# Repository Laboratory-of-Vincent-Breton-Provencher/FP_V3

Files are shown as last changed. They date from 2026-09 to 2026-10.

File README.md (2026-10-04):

# Multi-fiber Fiber Photometry System (FP V3)

A fiber photometry system that records from more than one fiber at a time. The system 
was developed by the VBP lab and has been in use since 2022.

If you use the system in your research **please cite:**
Bouchard S, Boutin J, Lévesque M, et al. *Region-specific weighting of sensory intensity
and reward prediction error by dopamine signals.* iScience, 2026; 29.
https://doi.org/10.1016/j.isci.2026.117130

> A STAR Protocols paper for using this system, implanting the fibers, and training head-fixed
> mice is in preparation.

---

## Contents

- [1. System overview](#1-system-overview)
- [2. Repository contents](#2-repository-contents)
- [3. Optical path](#3-optical-path)
- [4. Electronics](#4-electronics)
- [5. Software installation](#5-software-installation)
- [6. First-time configuration](#6-first-time-configuration)
- [7. Recording](#7-recording)
- [8. Output data](#8-output-data)
- [9. Validating a recording](#9-validating-a-recording)
- [10. Troubleshooting](#10-troubleshooting)
- [11. Known limitations and to-do](#11-known-limitations-and-to-do)

---

## 1. System overview

<p align="center">
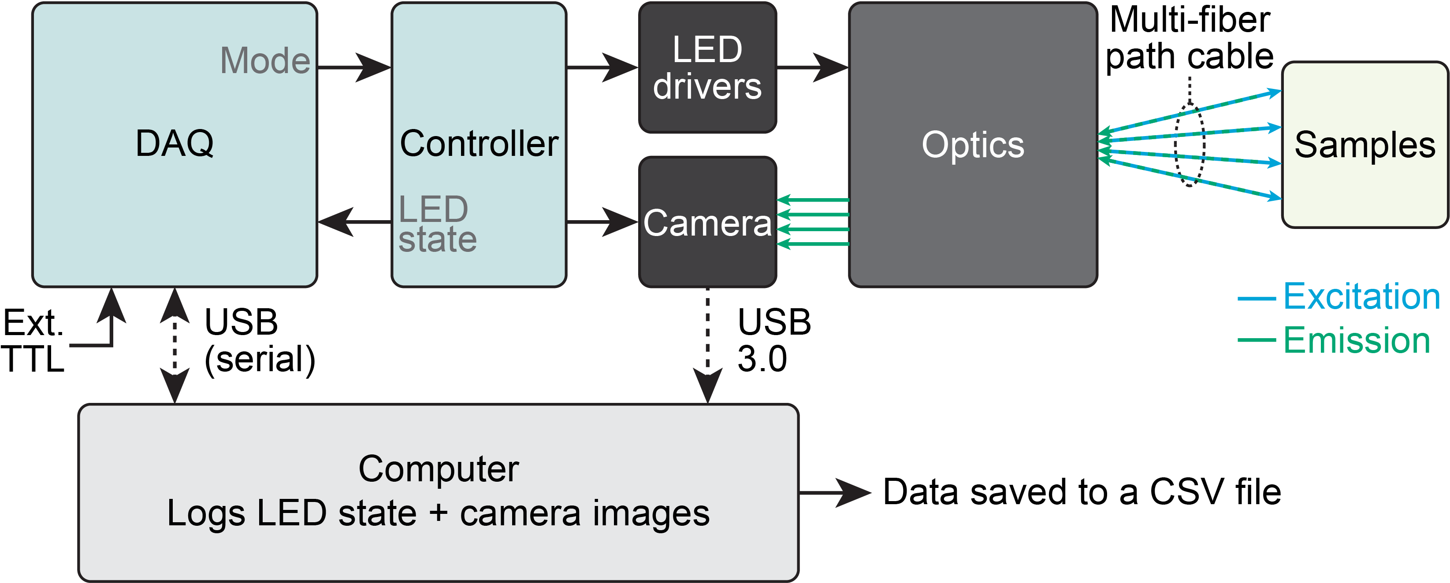
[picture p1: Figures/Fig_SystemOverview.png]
Overview


**Figure 1. Overview of system components**
</p>

Two microcontrollers, a camera and a set of LED drivers run the system, with a computer recording the result.

The **DAQ** (Arduino UNO) is the only board connected to the computer. It receives the requested mode from 
Bonsai over USB and passes it to the controller. It also reads the LED sate from the controller and sends it to the computer,
together with the state of an external TTL input (D8) for events from a behaviour system.

The **controller** (Arduino Nano) triggers the **camera** and switches the **LED drivers** so that each frame is illuminated 
by exactly one wavelength.

The **optics** focus the light sources (405 and 470 nm) onto the back of a multi-core patch cable, and the fluorescence 
emitted by the sample returns along the same path to the camera.

The **computer** runs a Bonsai script to extract the mean intensity inside one ROI per fiber and pair it with the LED state, 
and writes everything to a CSV file. 

<p align="center">
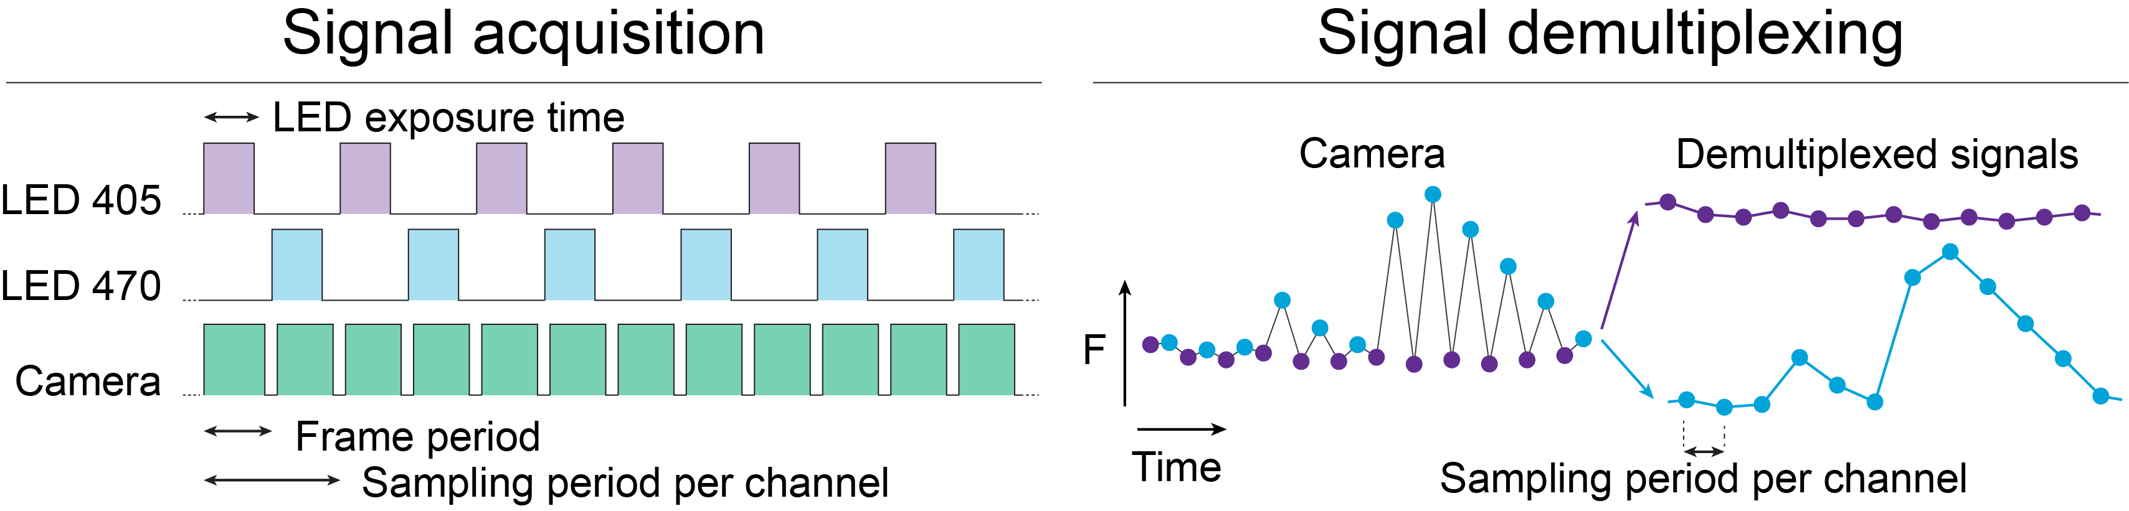
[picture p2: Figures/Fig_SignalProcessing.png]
Signal processing


**Figure 2. Signal acquisition and demultiplexing.**
</p>

The controller triggers the camera at 40 Hz and alternates the LEDs so that each frame 
is illuminated by exactly one wavelength. The exposure sits inside the LED pulse, and 
each wavelength is therefore acquired at 20 Hz. 

The raw intensity measured in one fiber ROI alternates between the two wavelengths from 
frame to frame. Because the state of every LED is recorded alongside each frame, the trace 
is split afterwards into one signal per wavelength.

---

## 2. Repository contents

| File | Purpose |
|---|---|
| `FP_camLED_controller.ino` | Controller sketch (Arduino **Nano**). Camera trigger and LED sequencing. |
| `FP_DAQ.ino` | DAQ sketch (Arduino **UNO**). Mode control, per-frame logging, external TTL. |
| `CustomFP_1chan_4Fibers.bonsai` | Bonsai workflow: camera, ROI extraction, serial parsing, CSV writing, live display. |
| `Part Lists/Optical paths.xlsx` | Optical components. |
| `Part Lists/Electronics.xlsx` | Electronic components. |
| `3D print/` | Cases and holders for the Arduinos and the protoboard. |

> **TODO:** add the wiring diagram, an optical path drawing, a photo of the setup, and the
> SpinView settings screenshots (Settings, Image Format, GPIO).

---

## 3. Optical path

<p align="center">
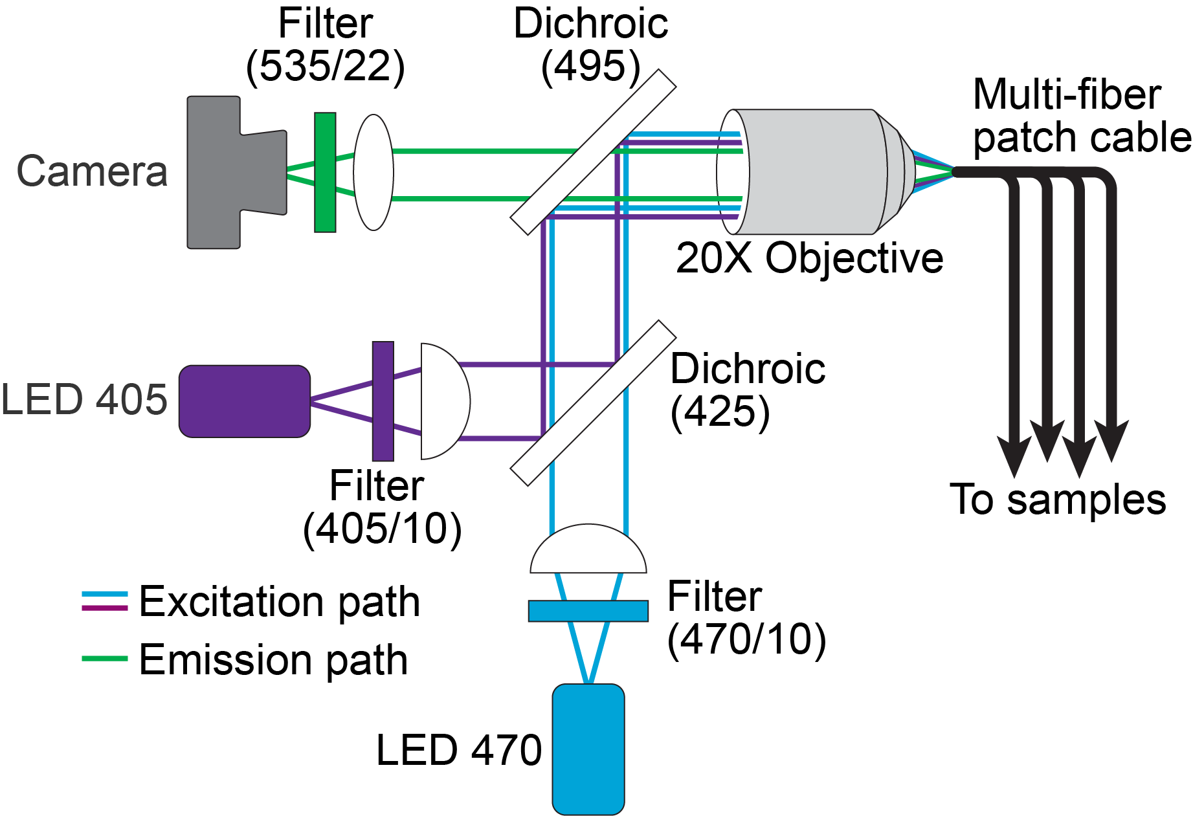
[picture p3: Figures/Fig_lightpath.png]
Optical path

</p>

**Figure 3. Optical path.**

Excitation light from a 405 nm LED (isosbestic reference) and a 470 nm LED (signal) passes
through a bandpass filter and a collimating lens (plano-convex, 25 mm focal length). A
longpass dichroic (425 nm) combines the two beams. A second longpass dichroic (495 nm), 
reflects them into the objective (10X air NA 0.25, or 20X air NA 0.4) and
into the fiber.

Light emitted by the specimen returns along the same path, passes through the 495 nm
dichroic, and is filtered by a bandpass filter before reaching the sCMOS camera through 
an achromatic tube lens.

The 405 nm channel serves as the isosbestic point for most sensors, and is used
to correct the 470 nm signal for motion artefacts. With green detection around 535 nm, the
system works with calcium sensors such as GCaMP, and with neuromodulator
sensors such as GRAB-DA or nLightG.

### Assembly

See the [list of optical components](Part%20Lists/Optical%20paths.csv).

<p align="center">
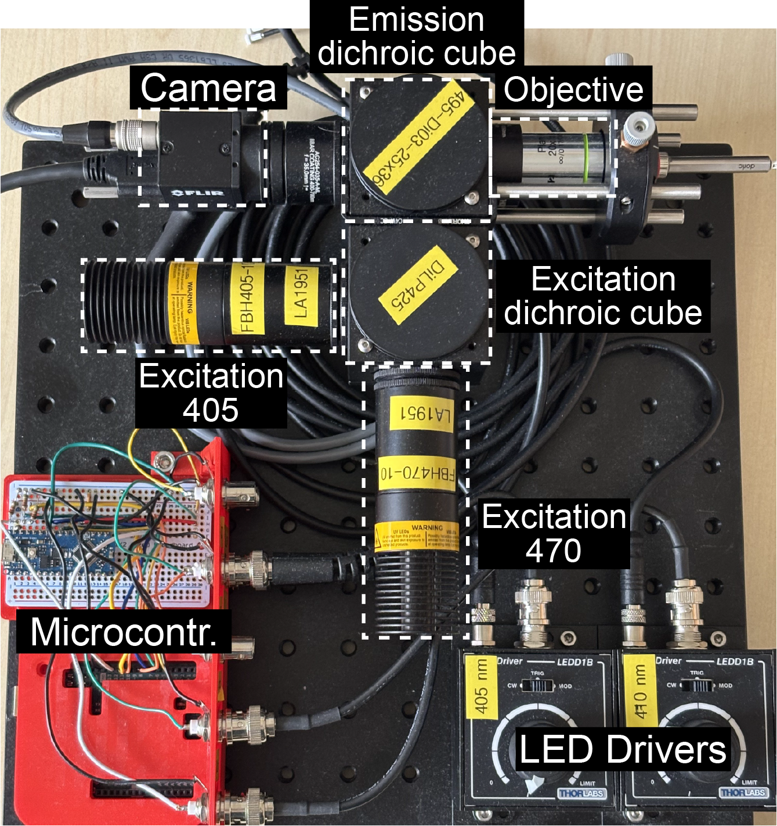
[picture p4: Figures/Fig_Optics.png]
Optic setup

</p>

**Figure 4. The assembled set up.** The optical path, the LED drivers and the microcontrollers
mounted on a single breadboard.

1. **Assemble both dichroic cubes** (Thorlabs #C4W). Fix the bottom plates (B1C). Attach the
   dichroic filter holder (FFM1) to the rotating platform (B3C) and temporarily fix each
   platform on top of the cubes. Join the cubes with the C4W-CC piece. Mount the cubes on
   the breadboard with optical posts.
2. **Build the excitation arms.** In a 1½ inch lens tube, insert the bandpass filter for that wavelength. 
   Add the collimating lens, flat side toward the LED, about 25 mm
   from the source, which is its focal length. Note that a Thorlabs mounted LED sits
   slightly inside the tube; use its spec sheet to calculate the position within the tube.
   Thorlabs spanner tools have graduations that help.

   To check collimation, hold the finished tube about 50 cm from a wall and turn the LED
   on: the spot should be roughly the same diameter as the tube's aperture (1 inch) and
   should not change noticeably as you move the tube closer or further away. A spot that
   grows with distance means the lens is too close to the LED; one that converges first
   means it is too far.
   
   Screw each tube into its cube using a
   lens tube coupler with two retaining rings (SM1T2), then add the mounted LEDs.
3. **Install the dichroics.** Insert the dichroics on each rotating platform (see step 1). The coated side must face
   the light sources. Adjust the angle of each dichroic so that both LEDs reach the
   back aperture of the objective.
4. **Assemble the objective and fiber adapter**. Screw a short lens tube into the cube, then
   the objective adapter around the objective and into the tube. The objective must be
   tight and immobile. Add the cage mount and the fiber adapter.
5. **Assemble the emission path**. Screw in a lens tube coupler with two retaining rings (SM1T2) to the emission dichroic cube.
   Screw in the achromat lens (already mounted in a tube). Insert a
   bandpass filter in a short lens tube and screw next to the achromat, and then the camera. 

### Alignment

Perform these alignment steps in the dark. The target output is **30–50 µW per fiber per
wavelength**, and the fiber bundle must stay inside the camera frame throughout.

1. **Align the dichroics.** Remove the fiber adapter (CXY1A) and place a power meter in
   front of the objective. Turn on the 470 nm LED only and adjust the angle of the 495
   dichroic to maximise the power at the objective, then secure its rotating plate. Next, turn on the 405 nm
   LED only and adjust the angle of the 425 dichroic to maximise the power. Keep this order: the 470 nm path depends only on the 495 dichroic, whereas
   the 405 nm path passes through both.
2. **Focus the fiber adapter on the camera.** Put the fiber adapter back in place and
   connect an optical patch cable. Slide the adapter along the cage rods to move it in Z
   until the fiber face is in focus on the camera, then secure it in place.
3. **Maximise the power in one fiber.** With a single fiber connected, adjust x and y with
   the CXY1A screws to maximise the output power. Repeat for every wavelength. The optimum
   position may differ slightly between 405 and 470 nm; in that case, split the difference
   between the two.
4. **Balance the fibers.** With several fibers connected, repeat step 3 to minimise the
   power differences between them.

---

## 4. Electronics

You will need a half-size protoboard, female BNC connectors and cables. See the [list of electronics](Part%20Lists/Electronics.csv). 
The case is 3D printed; the model is [available here](3D%20print/).

<p align="center">
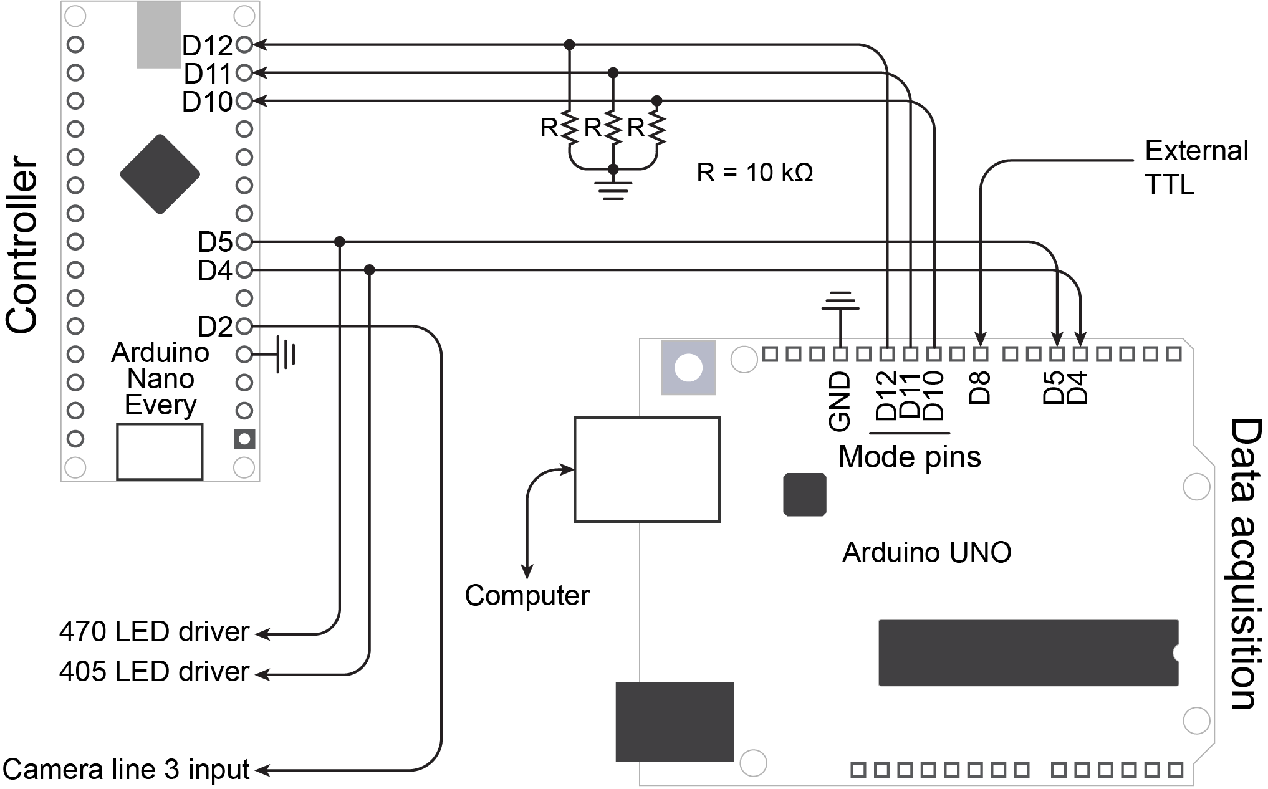
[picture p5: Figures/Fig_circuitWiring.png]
Wiring

</p>

**Figure 5. Circuit wiring.** Note: all components should be connected to a common ground.

### 4.1 Controller (Arduino Nano) — `FP_camLED_controller.ino`

Reads the requested mode on D10–D12 and drives the camera and the LED drivers on a fixed
40 Hz schedule. Upload once; it then runs from any USB power source. LED drivers need to be running in trigger mode (TRIG).

| Pin | Direction | Connected to |
|---|---|---|
| D2 | out | Camera trigger (both cameras, Line 3 in SpinView).  For more pin info [click here](https://softwareservices.flir.com/BFS-U3-50S5/latest/50-Quality/GPIOTest.htm)|
| D4 | out | 405 nm LED driver, and DAQ D4 |
| D5 | out | 470 nm LED driver, and DAQ D5 |
| D10, D11, D12 | in | Mode lines V, B, G from DAQ D10, D11, D12 |
| GND | — | Common ground with DAQ, camera and LED drivers |

Frame timing at 40 Hz:

```
        │◄────────────── 25.000 ms ──────────────►│
  LED   ┌──────────────────────────────┐          ┌───────────────
        │        24.5 ms excitation    │  500 µs  │  next LED
  ──────┘                              └──────────┘
 Trigger ──────┐                              ┌──────────────────
  (D2)         │  LOW while the LED is on     │
               └──────────────────────────────┘
        ▲ frame start (FALLING edge)
```

### 4.2 DAQ (Arduino UNO) — `FP_DAQ.ino`

Connected to the computer over USB. It sets the mode for the controller, watches the LED
driver lines, and prints one line per frame at **250000 baud**.

| Pin | Direction | Connected to |
|---|---|---|
| D4, D5 | in | Controller's 405 / 470 driver lines |
| D8 | in | External TTL (e.g. trial start from a behaviour system) |
| D10, D11, D12 | out | Mode lines V, B, G to controller D10, D11, D12. These required pull-down resistors (10 kΩ to ground). |
| GND | — | Common ground |

### 4.3 Modes and serial commands

Send one character to the DAQ, from Bonsai or from the Arduino IDE serial monitor. Upper or
lower case; anything else, including line endings, is ignored.

| Command | Mode (VBG) | LEDs cycled, one per frame | Per-channel rate at 40 fps |
|---|---|---|---|
| `0` | 000 | OFF | — |
| `V` | 100 | 405 | 40 Hz |
| `B` | 010 | 470 | 40 Hz |
| `G` | 001 | 565 | 40 Hz |
| `Y` | 110 | 405, 470 | 20 Hz |
| `M` | 101 | 405, 565 | 20 Hz |
| `C` | 011 | 470, 565 | 20 Hz |
| `X` | 111 | 405, 470, 565 | 13.3 Hz |

The system boots in OFF and stays there until a command arrives, so nothing is illuminated
or triggered until you ask for it. Changing mode restarts the LED cycle at the first
enabled wavelength, which is why each recording block starts on 405.

> **Note.** The controller and the DAQ implement modes for a third excitation source
> (565 nm), but the current setup uses only 405 and 470 nm. 
> 

### 4.4 Line format sent by the DAQ

One line per frame, emitted at the LED onset. There are 8 fields:

```
V,B,G,TTL,mode,FLAG,t_onset,t_ttl
1,0,0,0,110,07,283963284,0
```

| Field | Meaning |
|---|---|
| `V`, `B`, `G` | 1 for the LED that is on for this frame (read from the driver lines) |
| `TTL` | 1 if the external TTL is HIGH now, or rose at any point since the previous frame |
| `mode` | Commanded mode, 3 digits. May lead the LEDs by one frame at a mode switch |
| `FLAG` | Frame counter, 0–99, wraps. Detects lines lost on the serial link |
| `t_onset` | Arduino `micros()` at the LED onset of this frame |
| `t_ttl` | Arduino `micros()` of the TTL rising edge reported on this line, 0 if none |

---

## 5. Software installation

### 5.1 Arduino

1. Install the Arduino IDE.
2. In **Tools → Board → Boards Manager**, install the board package for your Nano. The system has been tested with the Nano Every board.
3. Upload `FP_camLED_controller.ino` to the **Nano** and `FP_DAQ.ino` to the **UNO**.
   Check the COM port for each before uploading. The controller only needs this once. Take note of the DAQ COM port. The COM port will be requested by the Bonsai script.
4. Test that the DAQ and the system can be driven without Bonsai: open the IDE serial monitor on the DAQ's port
   at **250000 baud** and type `Y` (two LEDs) or `X` (three LEDs), or `0` to stop.
   
### 5.2 Camera (Spinnaker)

1. Install `SpinnakerSDK_FULL_4.2.0.83_x64.exe`. This version works with the current
   Bonsai.Spinnaker package (see https://github.com/bonsai-rx/spinnaker). For VBP lab member, the installer is
   on our NAS. Other users should contact support at Teledyne as they no longer lists this version publicly.
2. Choose, the **full SDK** and the **Application Development** option. The GigE driver
   component can be deselected.
3. Connect the camera and confirm it streams in SpinView.
4. Apply the settings below. Anything not listed stays at its default; the Imaging Format, Processing,
   Sequencer and Features tabs are not modified.
5. Save the configuration as a user set in the camera so it survives a reconnection.

Reference configuration, for a **Blackfly S BFS-U3-04S2M** (firmware 1707.1.6.0):

**Settings tab**

| Setting | Value | Why |
|---|---|---|
| Acquisition Mode | Continuous | |
| Acquisition Frame Rate Enable | unchecked | The frame rate comes from the controller's trigger, not the camera |
| Exposure Mode | Timed | Exposure length is set here, not by the trigger pulse width |
| Exposure Auto | Off | Must be fixed, or the two wavelengths are exposed differently |
| Exposure Time | 16999 µs | Must fit inside the 24.5 ms LED pulse 17ms is what we commonly use. Issues with dropped frame increases with exposure time. |
| Gain Auto | Off | Must be fixed, for the same reason as exposure |
| Gain | 34.3 dB | Adjust per setup; see the note below |
| Gamma Enable | unchecked | Keeps the response linear, which fluorescence quantification requires |
| Black Level | 0 % | |
| Device Link Throughput Limit | 60000000 | |

**GPIO tab**

| Setting | Value | Why |
|---|---|---|
| Trigger Selector | Frame Start | |
| Trigger Mode | On | |
| Trigger Source | Line 3 | The controller's D2 output |
| Trigger Activation | Falling Edge | The trigger line idles HIGH and goes LOW for the excitation window |
| Trigger Overlap | Off | |
| Trigger Delay | 9 µs | Minimum permitted value |
| Line Selector / Line Mode | Line 0 / Input | |

### 5.3 Bonsai

Install Bonsai (tested with **2.9.1**): https://bonsai-rx.org/docs/articles/installation.html

In **Tools → Manage Packages**, install:

- `Bonsai.Spinnaker`
- `Bonsai.Vision`
- `Bonsai.Vision.Design`
- `Bonsai.Scripting.Expressions`
- `Bonsai.Gui`
- `Bonsai.Gui.ZedGraph`

---

## 6. First-time configuration

Close the serial monitor in the Arduino IDE before running Bonsai — only one program can
hold the port.

Open `CustomFP_1chan_4Fibers.bonsai` and set:

1. **Camera serial number** in the `SpinnakerCapture` node (dropdown).
2. **COM port** of the DAQ, in the `String` node feeding the `Arduino COM Port` subject
   (see step 5.1.3).
3. **Recording length** in the `N Frames` node. This is a total frame count, so at 40 fps:
   288000 = 2 h, 144000 = 1 h, 72000 = 30 min. Acquisition stops on its own at this count,
   and can also be stopped manually at any time, so set it longer than you expect to need.
4. **Start the workflow** with F5, or Workflow → Start. Check that the visualizer windows
   appear (see **Figure 6**); if they don't, which is usually the case the first time, see the note below.
5. **Turn the LEDs on** by pressing `Record`, so the fibers become visible. Without a mode
   command the LEDs stay off and the camera image is dark. The command can also be sent
   from the Arduino IDE serial monitor, but not while Bonsai holds the port.
6. **Fiber ROIs** in the `RoiActivity` node. Draw one ROI per fiber. ROI order sets the
   column names: ROI 0 → `f0_ch1`, and so on. Label each fiber physically with its ID and
   match the ROIs to those IDs. With fewer than four fibers, park the unused ROIs on an
   empty part of the image. 
   [More info on how to edit ROI here.](https://bonsai-rx.org/docs/api/Bonsai.Vision.RoiActivity.html) 
   Note: Changes to ROIs are only kept if you stop running Bonsai and save.
7. **Check for cross-talk:** block the light in front of one fiber and confirm that the
   other ROI values don't change.

**Note on visualizer windows**

<p align="center">
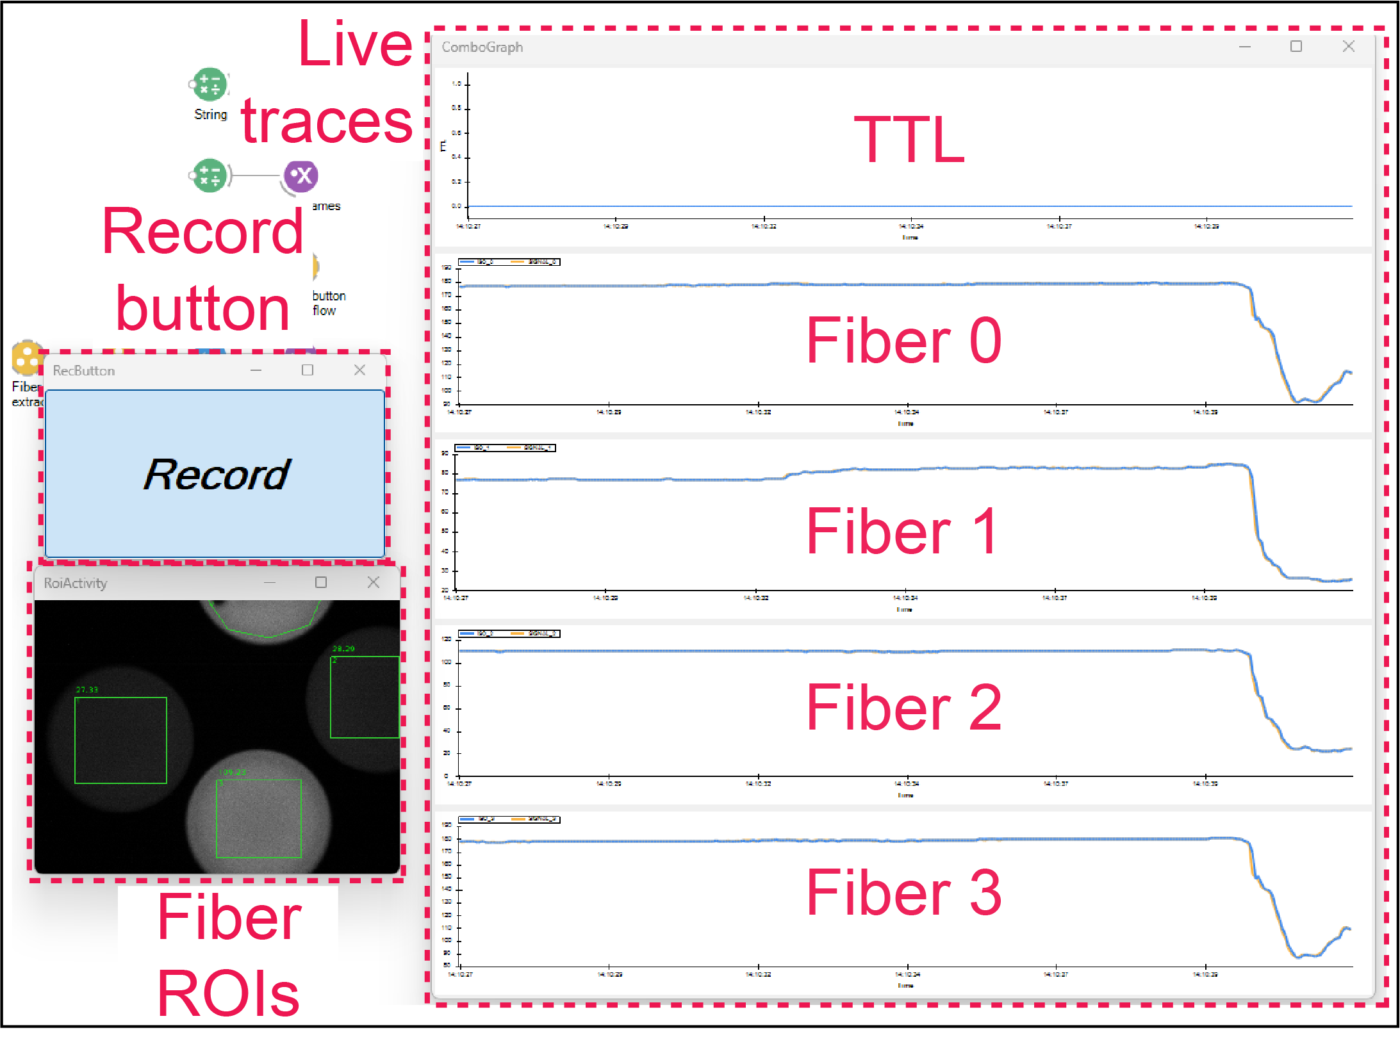
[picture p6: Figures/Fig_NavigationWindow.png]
Bonsai editor with the Explorer panel and the visualizer windows open
  
</p>

**Figure 6. Visualizer windows.** The Explorer panel, lower left, is used to navigate into
each group workflow; double-clicking a node there opens its visualizer while the workflow
runs.

The visualizer windows and their positions are stored in the
`CustomFP_1chan_4Fibers.bonsai.layout` file. If the graphs or the record button do not
appear when you start the workflow, that file is missing or out of date, and the windows
have to be opened manually:

| Window | Where | Node to double-click |
|---|---|---|
| Live traces | `Display Graph` | `ComboGraph` |
| Record button | `Rec button workflow` | `RecButton` |
| Fiber ROIs | `Fiber ROI extraction` | `RoiActivity` |

Use the Explorer panel in the lower left corner to navigate into each group. The workflow
must be running for a visualizer to open.

If double-clicking `ComboGraph` opens an empty window, the individual graphs have to be
added to it: drag each `RollingGraph` node from the `Display Graph` workflow onto the
`ComboGraph` window, starting from the top one (TTL) so they appear in the intended order.

Once all the windows are open and positioned, stop the workflow and save it (Ctrl+S) so
the layout is remembered for next time.

---

## 7. Recording

**Before recording:** Connect the fibers to the fiber adapter. With the LED driver set to 
constant current mode (CW), measure the **470 nm** output of each fiber. Adjust each of them 
into the 30–50 µW range. Put back to LED driver to trigger mode (TRIG).

1. Connect the fibers to the implanted ferrules.
2. Adjust the power on the **405 nm** channel:
   2a.Start the Bonsai workflow and press the **Record** toggle button. This sends `Y` (405/470) to the DAQ and starts the LEDs,
      the camera and the CSV writing.
   2b. Adjust the **405 nm** channel with its knob until its trace matches the 470 nm trace in
      the live graphs.
   2c. Press the **Record** toggle again to stop. Stop the Bonsai workflow and delete the files that were saved during the adjustment.
3. Start the Bonsai workflow.
4. Press the **Record** toggle button. This sends `Y` (405/470) to the DAQ and starts the LEDs,
   the camera and the CSV writing.
5. During the recording, watch the live traces and check that TTLs are being detected. If TTLs are to be recorded, confirm the cable is connected to DAQ D8.
6. Press **Record** again to stop. This sends `0`, which stops the LEDs and the triggers.
7. **Stop the Bonsai workflow.** A new CSV is only created when the workflow starts, so
   leaving it running puts the next recording in the same file.

Toggling the record button on and off during a session is safe. Each block appears in the
CSV as a continuous run of frames, separated by a gap in the timestamps, and each block
starts on 405.

---

## 8. Output data

One CSV per workflow run, named `FP_1ch_<timestamp>.csv`, with a header row.

| Column | Source | Meaning |
|---|---|---|
| `V`, `B`, `G` | DAQ | LED on for this frame |
| `TTL` | DAQ | External TTL state, as described above |
| `mode` | DAQ | Commanded mode |
| `ts_arduino` | DAQ | `micros()` at the LED onset |
| `ts_arduino_ttl` | DAQ | `micros()` of the TTL rising edge, 0 if none |
| `ts_ch1` | Camera | Camera chunk timestamp, in nanoseconds |
| `f0_ch1` … `f3_ch1` | Camera | Mean pixel intensity in each fiber ROI |
| `Channel` | Bonsai | `405`, `470` or `565`, derived from V/B/G |

To split violet and blue, filter on `Channel` rather than on row parity: the sequence
restarts at 405 after every mode change, so parity is not reliable across blocks.

**Choose one clock and stay with it.** The Arduino and camera clocks differ by roughly
470 ppm, which is about 3.4 s over a 2 hour recording. `ts_ch1` is the one attached to the
images and is the better choice for analysis. `ts_arduino` is the right one for lining up
external TTL events, since `ts_arduino_ttl` comes from the same clock.

> **Note** We need to add info on how signal is processed. Also include a python script for showing basic processing of data.

---

## 9. Validating a recording

**Channel labelling.** The camera is configured to trigger on the falling edge, which is
the start of the excitation window, so each image corresponds to the LED named on its own
row. Re-check this after any change to the trigger settings or to the controller sketch:
run in `Y` mode and block the 405 nm LED, or turn its driver output down to zero. In the
CSV, every row labelled `405` should then be dark and every `470` row bright. If the dark
rows carry the `470` label instead, the images are offset by one frame from their labels,
which means the trigger activation has been switched to the rising edge.

**Dropped frames.** Within a continuous block, consecutive `ts_arduino` values should
differ by 25000 µs. A 50000 µs step means a frame was lost. Gaps of hundreds of
milliseconds are just the record button being toggled.

**Image and log alignment.** For every row, the change in `ts_arduino` and the change in
`ts_ch1 / 1000` should agree to within a few tens of microseconds. A sudden jump to a full
frame period means the image and log streams have slipped relative to each other, and the
file should be discarded.

**Saturation.** Check that no ROI sits at 255. An ROI mean of exactly 255.0 means every
pixel is saturated and that fiber carries no usable signal. Aim for means around 100–180
by adjusting LED power, exposure or gain. With 8-bit pixels, a mean of 252 leaves almost
no headroom for a fluorescence transient.

---

## 10. Troubleshooting

**One LED never lights, but the mode changes.** Read the V/B/G columns. If they cycle
through all three channels, the fault is downstream of the Arduino: driver power, driver
set to internal instead of TTL/external mode, a loose cable, or the LED itself. If they
only alternate between two, measure the mode line for the missing channel on the
controller side while sending the command.

**Old or truncated lines appear when the workflow starts.** Data left in the port from the
previous session. The workflow drops everything that arrives in the first moments
(`SkipUntil` with a `Timer`); increase the `DueTime` if lines still slip through. Always
press the record toggle off before stopping the workflow, so the DAQ isn't logging while
the port is closed.

**The camera does not trigger.** Check the trigger source is Line 3, the activation edge is
falling, the exposure is shorter than 24.5 ms, and that the camera and Arduino grounds are
connected.

---

## 11. Known limitations

-  **The camera-to-serial pairing is positional.** Images and log lines are matched by
   arrival order, not by timestamp. It has held up in testing, but a single dropped frame
   would offset everything after it, which is why the alignment check in section 9 matters.
-  **Note on dynamic range.** Mono8 gives 256 intensity levels. If your 
   recorded ROI values are sitting at or near 255, where a fluorescence
   transient is clipped and lost, lower the camera gain first. The gain also lowers noise. Then, lower the LED power. The camera supports **Mono16**, which would give
   considerably more headroom and is worth testing with the Bonsai workflow.

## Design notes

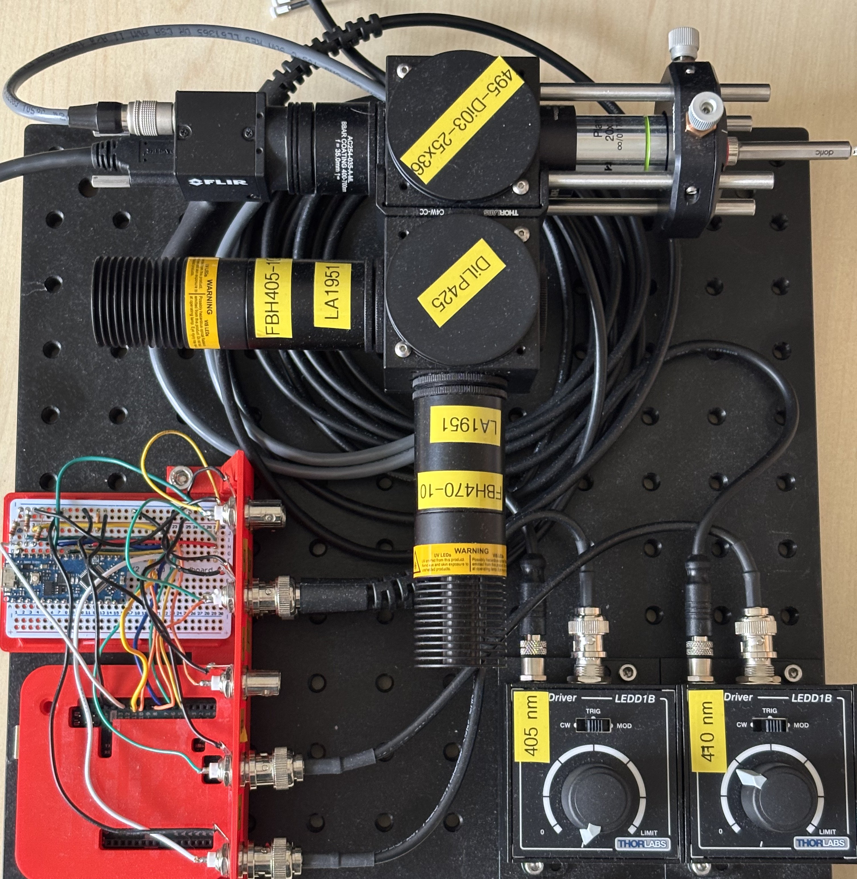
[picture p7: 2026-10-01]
Figures/Source/IMG_1036_cropped.jpg

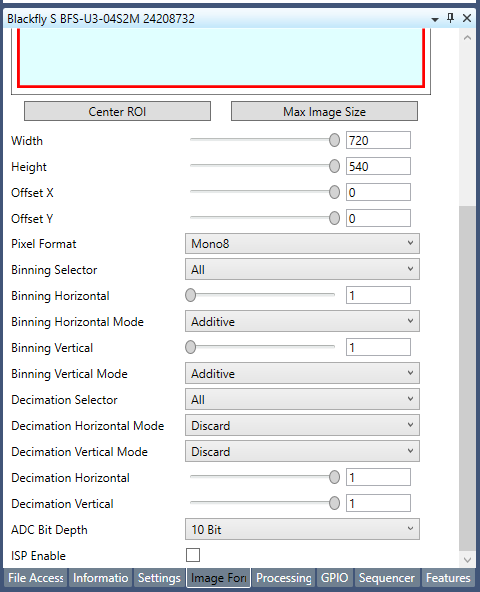
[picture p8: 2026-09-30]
CameraSettings/CameraSettings_3_ImgFormat.png

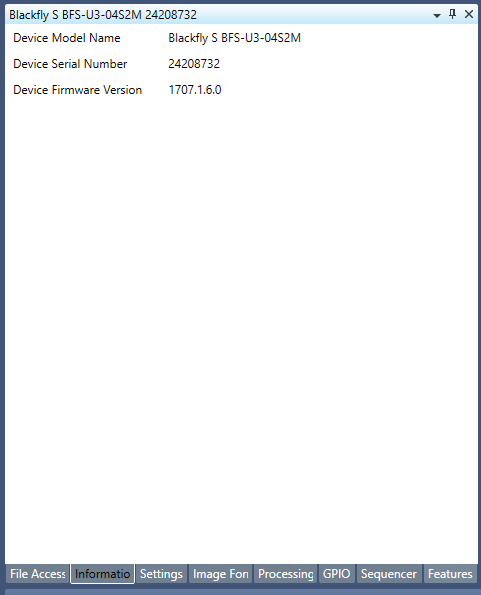
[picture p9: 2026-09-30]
CameraSettings/CameraSettings_1_Info.png

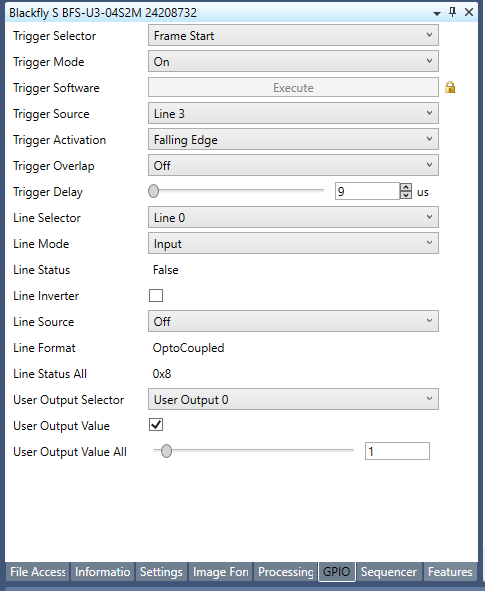
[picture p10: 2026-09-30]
CameraSettings/CameraSettings_5_GPIO.png

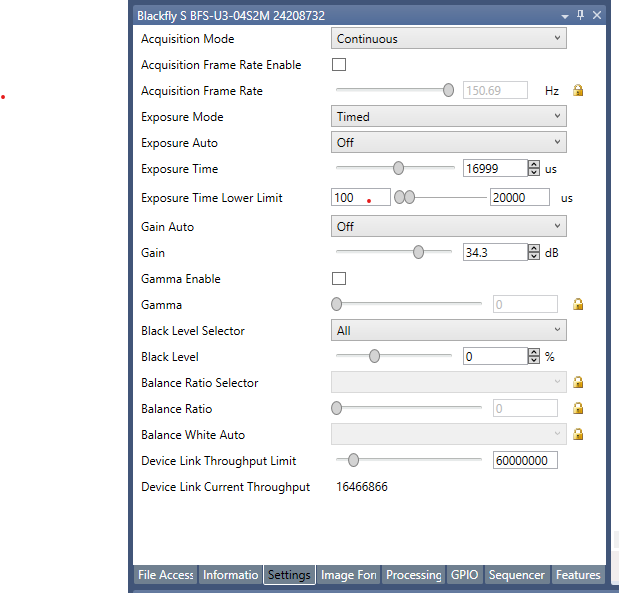
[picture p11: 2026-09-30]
CameraSettings/CameraSettings_2_Settings.png

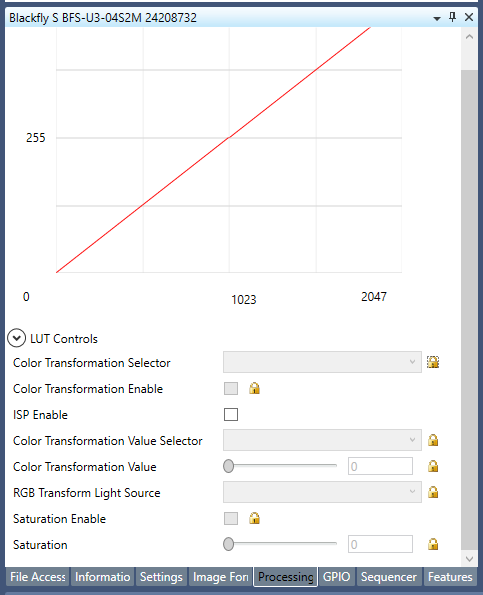
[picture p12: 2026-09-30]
CameraSettings/CameraSettings_4_Processing.png

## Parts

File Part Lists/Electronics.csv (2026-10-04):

Name | Link | Qty | Source | Cat # | Price each (USD)* | Total | Notes
COAX Cable BNC TO BNC 18" | https://www.digikey.ca/en/products/detail/amphenol-rf/115101-19-18-00/4947963 | 3 | Digikey | ARF2780-ND | $14.75 | $44.25
COAX CABLE BNC TO BNC 6' | https://www.digikey.ca/en/products/detail/amphenol-rf/115101-19-72-00/2504550 | 1 | Digikey | ACX1799-ND | $18.77 | $18.77
BNC RF Connectors / Coaxial Connectors BNC BULKHEAD RECPT 50 OHM 3.2PNL/THK | https://www.digikey.ca/en/products/detail/amphenol-rf/112424/1011723 | 10 | Digikey | ACX1046-ND | $2.92 | $29.16 | Need 8-10 depending on options
Hook-up Wire Spool Set - 22AWG Solid Core - 6 x 25 ft | https://www.digikey.ca/en/products/detail/adafruit-industries-llc/1311/6198255?gclsrc=aw.ds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 | 1 | Digikey | 1528-1743-ND | $15.95 | $15.95 | Adafruit # 1311
ARDUINO NANO EVERY WITH HEADERS | https://www.digikey.ca/en/products/detail/arduino/ABX00033/10239972 | 1 | Digikey | 1050-ABX00033-ND | $14.90 | $14.90
ARDUINO NANO STACKABLE HEADERS | https://www.digikey.ca/en/products/detail/sparkfun-electronics/16279/12178440 | 1 | Digikey | 1568-16279-ND | $2.51 | $2.51
ARDUINO UNO SMD R3 ATMEGA328 | https://www.digikey.ca/en/products/detail/arduino/A000073/3476357 | 1 | Digikey | 1050-1041-ND | $26.30 | $26.30
USB 2.0 A Male to USB 2.0 Micro Cable 6' | https://www.digikey.ca/en/products/detail/qualtek/3025031-06/6188813?gclsrc=aw.ds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 | 1 | Digikey | Q967-ND | $3.86 | $3.86
USB for uno | https://www.digikey.ca/en/products/detail/qualtek/3021007-06/1531291?gclsrc=aw.ds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 | 1 | Digikey | Q364-ND | $3.46 | $3.46
Half-size breadboard | https://www.digikey.ca/en/products/detail/adafruit-industries-llc/4539/12082396 | 1 | Digikey | 1528-4539-ND | $5.00 | $5.00
10 kOhm resistors | https://www.digikey.ca/en/products/detail/stackpole-electronics-inc/CF14JT10K0/1741265 | 3 | Digikey | CF14JT10K0CT-ND | $0.10 | $0.30
3D printed holder |  |  |  |  |  |  | See folder
 |  |  |  | Total |  | $164.46

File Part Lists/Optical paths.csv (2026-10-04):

Name | Link | Qty | Source | Cat # | Price each (USD)* | Total | Notes
T-Cube LED Driver, 1200 mA Max Drive Current | https://www.thorlabs.com/item/LEDD1B | 2 | Thorlabs | LEDD1B | $380.04 | $760.08
Power Supply Unit with 3.5 mm Jack Connector for One K- or T-Cube 15 V, 2.66 A | https://www.thorlabs.com/item/KPS201 | 2 | Thorlabs | KPS201 | $43.15 | $86.30
470 nm, 809 mW (Min) Mounted LED, 1000 mA | https://www.thorlabs.com/item/m470l5 | 1 | Thorlabs | M470L5 | $261.20 | $261.20
Ø1" Bandpass Filter, CWL = 470 ± 2 nm, FWHM = 10 ± 2 nm | https://www.thorlabs.com/item/FBH470-10 | 1 | Thorlabs | FBH470-10 | $193.82 | $193.82
405 nm, 1000 mW (Min) Mounted LED, 1000 mA | https://www.thorlabs.com/item/M405L4?aID=a056b4baa5de84c94eeb4c008f644e86&aC=1 | 1 | Thorlabs | M405L4 | $274.16 | $274.16
Hard-Coated Bandpass Filter, Ø25 mm, CWL = 405 nm, FWHM = 10 nm | https://www.thorlabs.com/item/FBH405-10?aID=72a807b1ebba4cd8c32fe8aa78364fae&aC=1 | 1 | Thorlabs | FBH405-10 | $193.82 | $193.82
N-BK7 Plano-Convex Lens, Ø1", f = 25 mm, Uncoated | https://www.thorlabs.com/item/LA1951?aID=9504e5e6d022440e60bb8b6b7970e9ba&aC=1 | 2 | Thorlabs | LA1951 | $28.95 | $57.90
SM1 Lens Tube, 1.50" Thread Depth | https://www.thorlabs.com/item/SM1L15 | 2 | Thorlabs | SM1L15 | $18.17 | $36.34
SM1 Retaining Ring for Ø1" Lens Tubes and Mounts, 10 Pack | https://www.thorlabs.com/item/SM1RR-P10 | 1 | Thorlabs | SM1RR-P10 | $46.88 | $46.88
SM1 (1.035"-40) Coupler, External Threads, 0.5" Long, Two Locking Rings | https://www.thorlabs.com/item/SM1T2 | 3 | Thorlabs | SM1T2 | $25.29 | $75.87 | 3rd one for the camera
30 mm Cage Cube | https://www.thorlabs.com/item/C4W | 2 | Thorlabs | C4W | $75.32 | $150.64
Externally SM1-Threaded End Cap | https://www.thorlabs.com/item/SM1CP2 | 2 | Thorlabs | SM1CP2 | $22.13 | $44.26
Blank Cover Plate | https://www.thorlabs.com/item/B1C | 2 | Thorlabs | B1C | $23.39 | $46.78
Fixed Cage Cube Platform for C4W/C6WR | https://www.thorlabs.com/item/B3C | 2 | Thorlabs | B3C | $31.02 | $62.04
30-mm-Cage-Compatible Rectangular Filter Mount | https://www.thorlabs.com/item/FFM1 | 2 | Thorlabs | FFM1 | $72.77 | $145.54
25 mm x 36 mm Longpass Dichroic Mirror, 425 nm Cut-On | https://www.thorlabs.com/item/DMLP425R | 1 | Thorlabs | DMLP425R | $298.70 | $298.70
30 mm Cage Cube Connector for C4W and C6WR Series Cubes | https://www.thorlabs.com/item/C4W-CC?aID=05cea842c430325db5eaebcb8b348e42&aC=1 | 1 | Thorlabs | C4W-CC | $64.20 | $64.20
Ø1/2" Optical Post, SS, 8-32 Setscrew, 1/4"-20 Tap, L = 2" | https://www.thorlabs.com/item/TR2 | 2 | Thorlabs | TR2 | $6.31 | $12.62
Ø1/2" Post Holder, Spring-Loaded Hex-Locking Thumbscrew, L = 2" | https://www.thorlabs.com/item/PH2 | 2 | Thorlabs | PH2 | $9.58 | $19.16
1/4"-20 Stainless Steel Setscrew, 5/8" Long, 25 Pack | https://www.thorlabs.com/item/SS25S0625 | 1 | Thorlabs | SS25S0625 | $7.46 | $7.46 | You only need two for attach the post holder to the breadboard
Cage Assembly Rod, 3" Long, Ø6 mm, 4 Pack | https://www.thorlabs.com/item/ER3-P4?aID=01b3557baf2733f4397297e08478e846&aC=2 | 1 | Thorlabs | ER3-P4 | $29.02 | $29.02
FC/PC Fiber Adapter Plate with External SM1 (1.035"-40) Threads, Wide Key (2.2 mm) | https://www.thorlabs.com/item/SM1FC | 1 | Thorlabs | SM1FC | $36.86 | $36.86
30 mm Cage System, XY Translating Lens Mount for Ø1" Optics | https://www.thorlabs.com/item/CXY1A?aID=5f6e1a3dfebfdd3d7206ff5e9ce5c25e&aC=1 | 1 | Thorlabs | CXY1A | $215.57 | $215.57
20X Evident Plan Achromat Objective, 0.40 NA, 1.2 mm WD | https://www.thorlabs.com/item/RMS20X?aID=2df9ef8807fd1ac0e8a50986c0c29f82&aC=1 | 1 | Thorlabs | RMS20X | $554.20 | $554.20 | Also tried with this objective but way more expensive: https://www.edmundoptics.ca/p/olympus-uplxapo-10x-objective/43024/
Adapter with External SM1 Threads and Internal RMS Threads | https://www.thorlabs.com/item/SM1A3 | 1 | Thorlabs | SM1A3 | $21.21 | $21.21
SM1 Lens Tube, 0.30" Thread Depth | https://www.thorlabs.com/item/SM1L03 | 1 | Thorlabs | SM1L03 | $14.07 | $14.07 | For holding the objective
535/22 nm BrightLine® single-band bandpass filter | https://www.idex-hs.com/store/product-detail/ff01_535_22_25 | 1 | IDEX Health & Science | FL-003976 | $318.78 | $318.78 | Semrock part #FF01-535/22-25
495 nm edge BrightLine® single-edge standard epi-fluorescence dichroic beamsplitter | https://www.idex-hs.com/store/product-detail/ff495_di03_25x36?search=true | 1 | IDEX Health & Science | FL-007145 | $308.66 | $308.66 | Semrock part # FF495-Di03-25x36
f=35 mm, Ø1" Achromatic Doublet, SM1-Threaded Mount, ARC: 400-700 nm | https://www.thorlabs.com/item/AC254-035-A-ML | 1 | Thorlabs | AC254-035-A-ML | $133.46 | $133.46
BFS-U3-04S2M-CS USB 3.1 Blackfly® S, Monochrome Camera | https://www.edmundoptics.ca/p/bfs-u3-04s2m-cs-usb3-blackflyreg-s-monochrome-camera/40161/ | 1 | Edmund Optics | 11-505 | $541.50 | $541.50 | Teledyne part # BFS-U3-04S2M-CS
Teledyne FLIR Type-A to Micro-B, USB 3.1 Locking Cable, 3m | https://www.edmundoptics.ca/p/usb-30-locking-cable-3m-length/29172/ | 1 | Edmund Optics | 86-770 | $41.00 | $41.00
Blackfly S/Blackfly 6-pin GPIO Hirose Connector Cable, 1m | https://www.edmundoptics.ca/p/blackflyreg-6-pin-gpio-hirose-connector-1m-cable/30349/ | 1 | Edmund Optics | 88-064 | $38.00 | $38.00
Aluminum Breadboard 12" x 12" x 1/2", 1/4"-20 Taps | https://www.thorlabs.com/item/MB12?aID=90c1048a0fb55e9c6df63419d38347cc&aC=2 | 1 | Thorlabs | MB12 | $184.47 | $184.47
1/4"-20 Stainless Steel Cap Screw, 1/2" Long, 25 Pack | https://www.thorlabs.com/item/SH25S050 | 1 | Thorlabs | SH25S050 | $10.11 | $10.11 | Need only a few
Low-Autofluorescence Fiber-optic Patch Cord | https://neuro.doriclenses.com/collections/branching-fiber-optic-patchcords | 1 | Doric Lenses | MFP_400/440/1100-0.37_2m_FC-MF1.25_LAF | $307.00 | $307.00 | 1 fiber option (price is from 2023)
Low-Autofluorescence Bundle Branching Fiber-optic Patch Cord | https://neuro.doriclenses.com/collections/branching-fiber-optic-patchcords | 1 | Doric Lenses | BBP(2)_400/440/900-0.37_2m_FCM-2xMF1.25_LAF | $552.30 | $552.30 | 2 fiber option (price is from 2023)
Low-Autofluorescence Bundle Branching Fiber-optic Patch Cord | https://neuro.doriclenses.com/collections/branching-fiber-optic-patchcords | 1 | Doric Lenses | BBP(4)_400/440/900-0.37_2m_FCM-4xMF1.25_LAF | $1,002.20 | $1,002.20 | 4 fiber option (price is from 2023)
Fluorescent Microscope Slide, Green, 1.7 mm Thick | https://www.thorlabs.com/fluorescent-microscope-slides-and-alignment-targets?tabName=Overview | 1 | Thorlabs | FSK2 | $6.05 | $6.05 | Optional
Standard Photodiode Power Sensor, Si, 400 - 1100 nm, 500 nW - 500 mW | https://www.thorlabs.com/item/S121C?aID=cf45f4c55a4530371cc6c6b2055d6093&aC=2 | 1 | Thorlabs | S121C | $414.38 | $414.38 | Other models can work
Optical Power and Energy Meter Console, 3.5" Touchscreen | https://www.thorlabs.com/item/PM100D2 | 1 | Thorlabs | PM100D2 | $1,350.00 | $1,350.00 | Other models can work
*: Updated September 2026 |  |  |  |  |  | $8,916.61

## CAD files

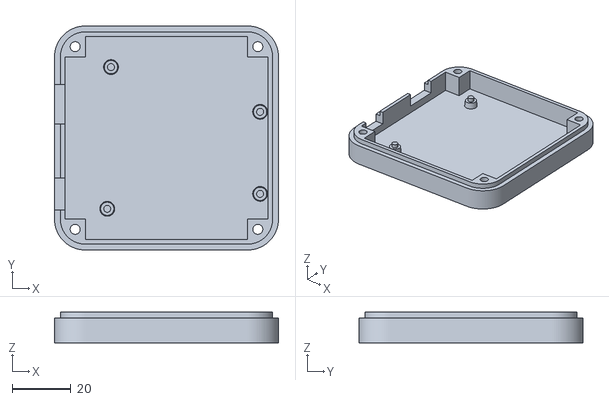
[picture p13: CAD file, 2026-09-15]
3D print/BNC Breakout Board And Arduino holder/uno_base.stl
76.3 x 76.3 x 10.5

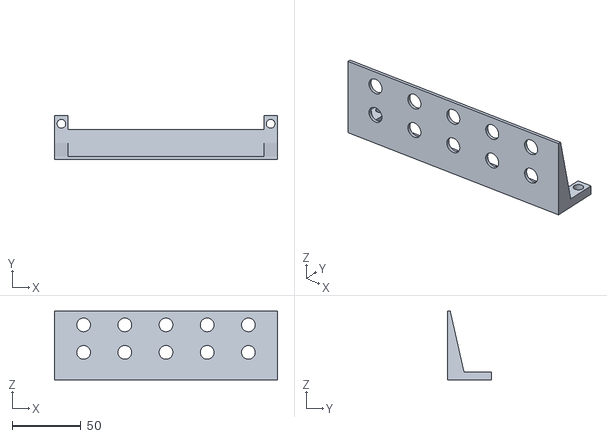
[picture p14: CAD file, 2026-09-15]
3D print/BNC Breakout Board And Arduino holder/Unnamed-Body.stl
162.4 x 32.0 x 50.0

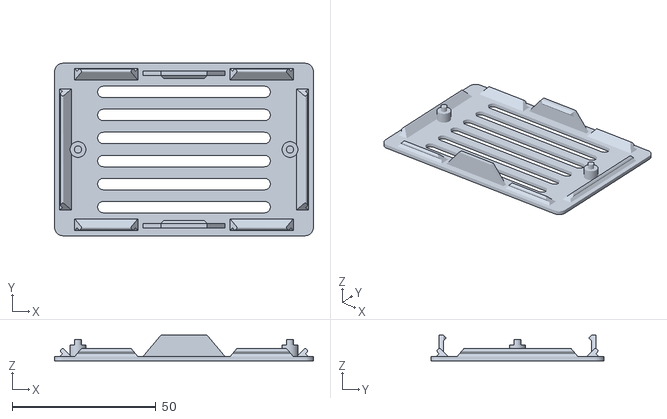
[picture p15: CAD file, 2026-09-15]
3D print/BNC Breakout Board And Arduino holder/protoboard_base.stl
90.0 x 60.0 x 9.00

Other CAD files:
3D print/BNC Breakout Board And Arduino holder/bnc wall.FCStd
3D print/BNC Breakout Board And Arduino holder/bottom-cover-halfsize.stl

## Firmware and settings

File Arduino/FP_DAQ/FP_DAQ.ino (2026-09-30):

// Data acquisition (Arduino UNO, ATmega328P): sets the controller's mode, logs
// which LED is on for every frame, and records an external TTL (e.g. trial start).
//
// Commands accepted over serial (from Bonsai), one character each, upper or lower case:
//
//   Command   Mode (VBG)   LEDs, cycled one per frame
//   '0'       000          OFF
//   'V'       100          410 only
//   'B'       010          470 only
//   'G'       001          565 only
//   'Y'       110          410 / 470
//   'M'       101          410 / 565
//   'C'       011          470 / 565
//   'X'       111          410 / 470 / 565
//
//   Anything else (e.g. \r \n from the line terminator) is ignored.
//   Requires the revised controller sketch; the original one only handled 110 and 111.
//
// Log line, one per frame (at the LED onset):
//   V,B,G,TTL,mode,FLAG                     (default, same format as before)
//   V,B,G,TTL,mode,FLAG,t_onset,t_ttl        (with LOG_TIMESTAMP = true)
//
//   TTL    = 1 if the external TTL is HIGH now OR rose at any time since the previous
//            logged frame. A level signal reads 1 for every frame of the trial, as before;
//            a short pulse can no longer be missed (it shows on the next frame's line).
//   t_onset = micros() at this frame's LED onset
//   t_ttl   = micros() of the TTL rising edge reported on this line, 0 if none
//
// NOTE: opening the serial port resets the UNO. For ~1-2 s the bootloader runs and
// any command sent in that window is lost. Have Bonsai wait ~2 s after opening the
// port before sending 'X' / 'Y'.

#include <Arduino.h>

// Mode at power-up / reset. OFF means nothing is triggered until Bonsai asks for it.
// Set to 110 to restore the old behaviour (acquisition starts as soon as the UNO boots).
const int START_MODE = 0;

// Adds t_onset and t_ttl columns. Leave false to keep the 6-column format Bonsai parses now.
const bool LOG_TIMESTAMP = true;

// OUTPUT PINS (mode-select lines to the controller Nano).
// D10, D11, D12 are PB2, PB3, PB4 on the ATmega328P; writeModePins() sets them in one write.
const uint8_t PINMODE_V = 10;
const uint8_t PINMODE_B = 11;
const uint8_t PINMODE_G = 12;

// INPUT PINS
// V/B/G tap the Nano's LED410/LED470/LED565 driver lines (ground truth for which LED is on).
const uint8_t V   = 4;
const uint8_t B   = 5;
const uint8_t G   = 6;
const uint8_t TTL = 8;  // external TTL; D8 = PB0 = PCINT0 (pin-change interrupt)

int mode = START_MODE;
int prevV = 0, prevB = 0, prevG = 0;
int FLAG = 0;  // 0-99, wraps; one tick per logged frame

// Set by the interrupt, cleared when reported in a log line
volatile bool ttlRose = false;
volatile unsigned long ttlRiseUs = 0;

// Pin-change interrupt for D8: fires on both edges, we keep only rising ones.
// Catches pulses of any length, even while the main loop is busy printing.
ISR(PCINT0_vect) {
  if (PINB & _BV(PB0)) {
    if (!ttlRose) ttlRiseUs = micros();  // keep the first rise since the last report
    ttlRose = true;
  }
}

// Set all three mode lines simultaneously, so the controller can never read a
// half-changed state (e.g. 100 while going from 000 to 110).
void writeModePins(int m) {
  uint8_t bits = 0;
  if (m / 100 % 10) bits |= _BV(PB2);  // V -> D10
  if (m / 10 % 10)  bits |= _BV(PB3);  // B -> D11
  if (m % 10)       bits |= _BV(PB4);  // G -> D12
  uint8_t mask = _BV(PB2) | _BV(PB3) | _BV(PB4);

  uint8_t sreg = SREG;
  cli();
  PORTB = (PORTB & ~mask) | bits;
  SREG = sreg;
}

void setup() {
  // 250000 baud divides 16 MHz exactly (0% error). Bonsai must use the same rate.
  Serial.begin(250000);

  // Set the output levels BEFORE making the pins outputs, so they never glitch.
  writeModePins(mode);
  pinMode(PINMODE_V, OUTPUT);
  pinMode(PINMODE_B, OUTPUT);
  pinMode(PINMODE_G, OUTPUT);

  pinMode(V, INPUT);
  pinMode(B, INPUT);
  pinMode(G, INPUT);
  pinMode(TTL, INPUT);  // add a 10k pull-down so an unplugged cable reads LOW

  // Enable the pin-change interrupt on D8 only
  PCMSK0 = _BV(PCINT0);
  PCIFR  = _BV(PCIF0);   // clear any stale flag
  PCICR |= _BV(PCIE0);
}

void loop() {
  // Non-blocking command handling: one byte per pass, pins are polled every pass.
  if (Serial.available()) {
    int c = Serial.read();
    int newMode = mode;
    // Modes are stored as decimal digits VBG. Don't write 011 or 001 here:
    // a leading 0 makes C++ read the number as octal (011 == 9).
    switch (toupper(c)) {
      case '0': newMode = 0;   break;  // OFF
      case 'V': newMode = 100; break;  // 410
      case 'B': newMode = 10;  break;  // 470
      case 'G': newMode = 1;   break;  // 565
      case 'Y': newMode = 110; break;  // 410 / 470
      case 'M': newMode = 101; break;  // 410 / 565
      case 'C': newMode = 11;  break;  // 470 / 565
      case 'X': newMode = 111; break;  // 410 / 470 / 565
      default:  break;                 // ignore \r, \n, stray bytes
    }
    if (newMode != mode) {
      if (mode == 0) {
        // Starting acquisition: forget TTL edges that happened while OFF,
        // so they aren't attributed to the first frame of the new run.
        uint8_t sreg = SREG;
        cli();
        ttlRose = false;
        SREG = sreg;
      }
      mode = newMode;
      writeModePins(mode);
    }
  }

  int valV = digitalRead(V);
  int valB = digitalRead(B);
  int valG = digitalRead(G);

  // Onset of a frame = rising edge on any LED line
  if ((valV && !prevV) || (valB && !prevB) || (valG && !prevG)) {
    unsigned long tOnset = micros();

    // Take and clear the latched TTL edge atomically
    uint8_t sreg = SREG;
    cli();
    bool rose = ttlRose;
    unsigned long tRise = ttlRiseUs;
    ttlRose = false;
    SREG = sreg;

    int valTTL = (digitalRead(TTL) == HIGH || rose) ? 1 : 0;

    Serial.print(valV);
    Serial.print(',');
    Serial.print(valB);
    Serial.print(',');
    Serial.print(valG);
    Serial.print(',');
    Serial.print(valTTL);
    Serial.print(',');
    // Commanded mode, zero-padded to 3 digits (e.g. 011); may lead the LEDs by one frame at a switch
    if (mode < 100) Serial.print('0');
    if (mode < 10)  Serial.print('0');
    Serial.print(mode);
    Serial.print(',');
    if (FLAG < 10) Serial.print('0');
    Serial.print(FLAG);
    if (LOG_TIMESTAMP) {
      Serial.print(',');
      Serial.print(tOnset);
      Serial.print(',');
      Serial.print(rose ? tRise : 0UL);
    }
    Serial.println();

    FLAG = (FLAG + 1) % 100;
  }

  prevV = valV;
  prevB = valB;
  prevG = valG;
}

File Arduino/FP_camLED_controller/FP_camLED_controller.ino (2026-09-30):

// Controller (Arduino Nano): camera trigger + LED sequencing.
// Mode is set by the acquisition Arduino (UNO) on D10/D11/D12.
//
// Mode pins (V B G):  000 OFF, 100 V, 010 B, 001 G, 110 VB, 101 VG, 011 BG, 111 VBG
// Enabled LEDs fire one per frame in the order 410 -> 470 -> 565, skipping disabled ones.

#include <Arduino.h>

// ---------------- Timing ----------------
const unsigned long FPS             = 40;                 // Hz (total, all channels)
const unsigned long FRAME_PERIOD_US = 1000000UL / FPS;    // 25000 us at 40 Hz
const unsigned long DARK_TIME_US    = 500;                // LEDs off + trigger HIGH between frames
const unsigned long T_EXCITATION_US = FRAME_PERIOD_US - DARK_TIME_US;
// DARK_TIME_US must leave room for the end-of-frame writes and the mode read (~250 us worst case).

// ---------------- Pins ----------------
const uint8_t CAM   = 2;   // Camera trigger, idle HIGH, LOW during exposure (Line 3 in SpinView)
const uint8_t LED_PINS[3]  = {4, 5, 6};    // 410, 470, 565 nm drivers
const uint8_t MODE_PINS[3] = {10, 11, 12}; // V, B, G (inputs from the UNO)

// ---------------- State ----------------
uint8_t mode       = 0;     // bitmask: bit0 = V, bit1 = B, bit2 = G
uint8_t ledIndex   = 0;     // next LED to try (0 = 410, 1 = 470, 2 = 565)
bool    running    = false;
unsigned long tStart = 0;   // scheduled start of the current frame

uint8_t readModePins() {
  uint8_t m = 0;
  for (uint8_t i = 0; i < 3; i++) {
    if (digitalRead(MODE_PINS[i]) == HIGH) m |= (1 << i);
  }
  return m;
}

// Accept a new mode only if it reads the same twice, 200 us apart.
// This rejects the in-between states seen while the UNO is changing its pins one at a time.
uint8_t readModeStable() {
  uint8_t m = readModePins();
  if (m != mode) {
    delayMicroseconds(200);
    if (readModePins() != m) return mode;  // still changing; keep the old mode this frame
  }
  return m;
}

uint8_t nextLed() {
  // mode is nonzero here, so this always finds an enabled LED
  while (!(mode & (1 << ledIndex))) ledIndex = (ledIndex + 1) % 3;
  uint8_t led = ledIndex;
  ledIndex = (ledIndex + 1) % 3;
  return led;
}

void setup() {
  // Set the level BEFORE making the pin an output, so CAM never drops LOW at boot
  // (pinMode(OUTPUT) alone drives LOW first, which is a falling edge = spurious trigger).
  digitalWrite(CAM, HIGH);
  pinMode(CAM, OUTPUT);

  for (uint8_t i = 0; i < 3; i++) {
    digitalWrite(LED_PINS[i], LOW);
    pinMode(LED_PINS[i], OUTPUT);
    pinMode(MODE_PINS[i], INPUT);  // add external pull-downs (e.g. 10k) so these don't float
  }
}

void loop() {
  // This runs in the dark period after the previous frame (or continuously while OFF)
  uint8_t newMode = readModeStable();
  if (newMode != mode) {
    mode = newMode;
    ledIndex = 0;  // restart the sequence at the first enabled LED
  }

  if (mode == 0) {
    running = false;
    return;
  }

  if (!running) {
    // First frame of a run: start now
    running = true;
    tStart = micros();
  } else {
    // Fixed schedule: next frame starts exactly one period after the last one,
    // so loop overhead doesn't accumulate as drift over long recordings.
    while (micros() - tStart < FRAME_PERIOD_US) {}
    tStart += FRAME_PERIOD_US;
  }

  uint8_t led = nextLed();

  digitalWrite(CAM, LOW);
  digitalWrite(LED_PINS[led], HIGH);

  while (micros() - tStart < T_EXCITATION_US) {}

  digitalWrite(CAM, HIGH);
  digitalWrite(LED_PINS[led], LOW);
}

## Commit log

2026-09-15 Part lists and 3d printed stuff
    [Electronics.xlsx, Optical paths.xlsx, Unnamed-Body.stl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]
2026-09-29 some update
    [Electronics.xlsx, Optical paths.xlsx]
2026-10-01 Providing csv as part lists
    [Electronics.csv, Electronics.xlsx, Optical paths.csv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]
2026-10-01 added circuit wiring
2026-10-04 Update Optical paths.csv
    [Optical paths.csv]
2026-10-05 Update wiring
2026-10-28 Fix arduino script so t_arduino resets
2026-11-12 Now saving frame ID for the camera.
    Now saving frame ID. This helps with tracking down sync issues with camera and arduino.
